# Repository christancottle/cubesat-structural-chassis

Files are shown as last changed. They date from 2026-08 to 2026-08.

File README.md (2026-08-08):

# CubeSat Structural Chassis

A CDS-compliant 1U CubeSat structural chassis — modeled, dimensioned, and structurally verified in SolidWorks over a two-week summer project. This covers the load-bearing subsystem of a CubeSat: the rail/wall chassis and internal mounting deck, built to the CalPoly CubeSat Design Specification (CDS) and verified against a launch load case using SolidWorks Simulation.

## Overview

The goal of this project was to design a real, spec-compliant CubeSat structure from scratch and take it through a complete engineering workflow: parametric CAD modeling, structural finite element analysis (FEA), a design iteration based on analysis results, and formal engineering drawings. This isn't a full CubeSat (no electronics, solar panels, or payload) — it's a focused structures deliverable, similar to what a "structures" subteam on a real CubeSat program would own.

## Design

- **Envelope:** 100 x 100 x 100 mm (1U CubeSat standard)
- **Rails:** 8.5 mm width per the CalPoly CubeSat Design Specification (minimum contact width for the P-POD dispenser), with 1 mm minimum corner fillets
- **Walls:** 1.5 mm thick aluminum panels connecting the rail posts
- **Mounting deck:** internal plate offset from the base, sized to clear the rail posts, with 4x M3 clearance holes (3.2 mm) near the corners for payload mounting
- **Material:** 6061-T6 aluminum

## Structural Analysis

**Load case:** 10g quasi-static axial acceleration (98 m/s²), representing a typical launch load factor along the tube's long axis — the same direction the rails travel through the P-POD dispenser.

**Fixtures:** the four outer side faces of the tube were fixed, as a simplification of the real rail-to-dispenser contact (the rails are flush with the walls on the outside, so the true contact patch can't be isolated as a separate face without additional split-line work — noted here as a known simplification).

**Contact:** the mounting deck is bonded to the surrounding tube structure, representing a fastened/mounted connection.

**Result:** maximum von Mises stress of 157.4 kPa against a yield strength of 275 MPa for 6061-T6 aluminum — a safety factor of roughly 1,750x.

| Design iteration | Wall thickness | Max stress | Safety factor |
|---|---|---|---|
| Baseline | 2.5 mm | 158.2 kPa | ~1,738x |
| Final | 1.5 mm (+ corner fillets added) | 157.4 kPa | ~1,747x |

**Key finding:** reducing wall thickness by 40% had almost no effect on peak stress. The mounting deck, not the tube walls, governs the peak stress in this load case — meaning the wall thickness has room for further mass optimization without compromising structural margin.

## Repository Contents

```
CAD/          SolidWorks part file (.SLDPRT) and STEP export
drawings/     Dimensioned engineering drawing (PDF)
analysis/     FEA result screenshots and summary
images/       Renders used in this README
```

## Future Work

- Use split-line features to isolate the true rail contact area for a more accurate fixture definition
- Explore relieved/L-shaped rail geometry for further mass savings
- Add additional load cases (lateral acceleration, random vibration)
- Model fasteners/standoffs explicitly rather than using a bonded contact simplification

## Tools

SolidWorks 2024/2025 (CAD), SolidWorks Simulation (FEA)

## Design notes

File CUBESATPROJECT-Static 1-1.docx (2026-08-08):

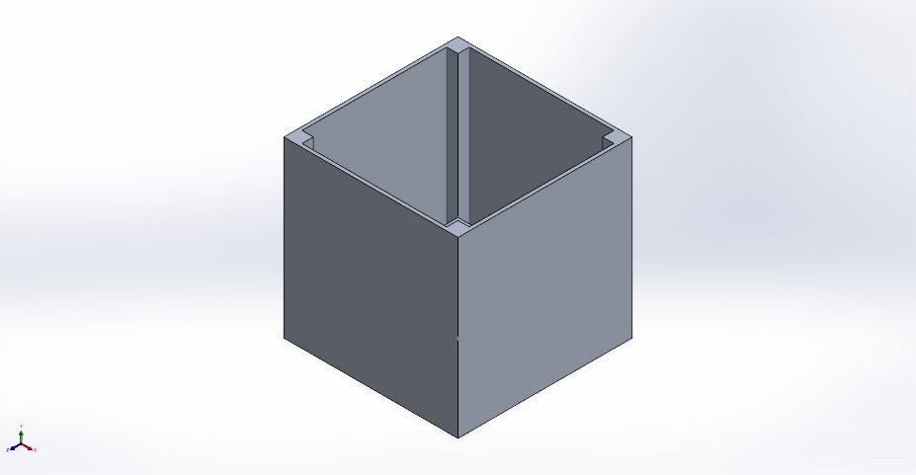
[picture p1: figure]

Simulation of CUBESATPROJECT

Date: Friday, August 7, 2026
Designer: Solidworks

Study name: Static 1

Analysis type: Static
Description No Data

# Assumptions

# Model Information

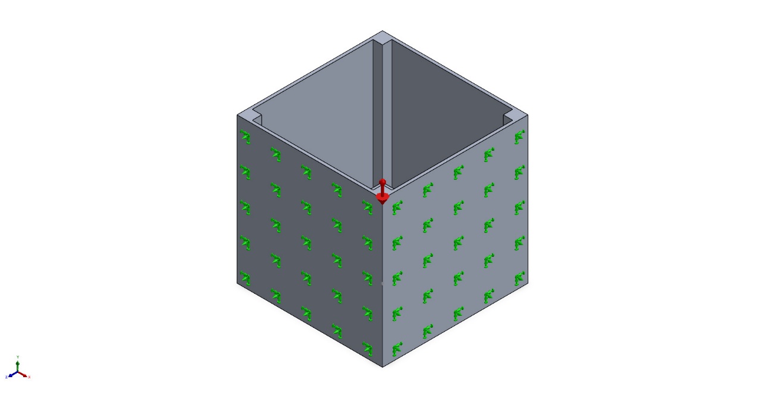
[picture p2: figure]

Model name: CUBESATPROJECT

Current Configuration: Default

Solid Bodies
Document Name and Reference | Treated As | Volumetric Properties | Document Path/Date Modified

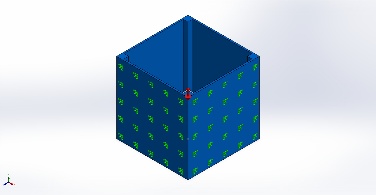
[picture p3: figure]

Boss-Extrude2 | Solid Body | Mass:0.25731 kg Volume:9.53e-05 m^3 Density:2,700 kg/m^3 Weight:2.52164 N | C:\Users\frxif\OneDrive\Documents\CUBESATPROJECT.SLDPRT Aug 6 16:11:20 2026

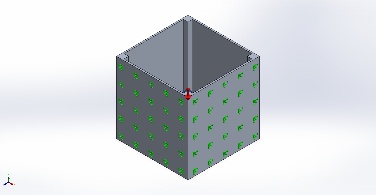
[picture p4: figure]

Boss-Extrude3 | Solid Body | Mass:0.0343863 kg Volume:1.27357e-05 m^3 Density:2,700 kg/m^3 Weight:0.336986 N | C:\Users\frxif\OneDrive\Documents\CUBESATPROJECT.SLDPRT Aug 6 16:11:20 2026

# Study Properties

Study name | Static 1
Analysis type | Static
Mesh type | Solid Mesh
Thermal Effect: | On
Thermal option | Include temperature loads
Zero strain temperature | 298 Kelvin
Include fluid pressure effects from SOLIDWORKS Flow Simulation | Off
Solver type | Automatic
Inplane Effect: | Off
Soft Spring: | Off
Inertial Relief: | Off
Incompatible bonding options | Automatic
Contact penalty stiffness scale factor | 1
Large displacement | Off
Compute free body forces | On
Friction | Off
Use Adaptive Method: | Off
Result folder | SOLIDWORKS document (C:\Users\frxif\OneDrive\Documents)

# Units

Unit system: | SI (MKS)
Length/Displacement | mm
Temperature | Kelvin
Angular velocity | Rad/sec
Pressure/Stress | N/m^2

# Material Properties

Model Reference | Properties | Components

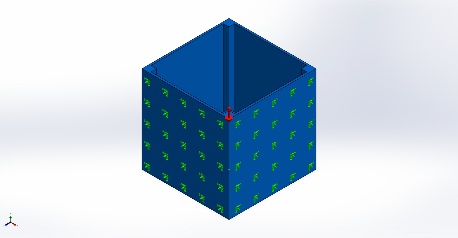
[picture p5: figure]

| Name: 6061-T6 (SS) Model type: Linear Elastic Isotropic Default failure criterion: Unknown Yield strength: 2.75e+08 N/m^2 Tensile strength: 3.1e+08 N/m^2 Elastic modulus: 6.9e+10 N/m^2 Poisson's ratio: 0.33 Mass density: 2,700 kg/m^3 Shear modulus: 2.6e+10 N/m^2 Thermal expansion coefficient: 2.4e-05 /Kelvin | SolidBody 1(Boss-Extrude2)(CUBESATPROJECT), SolidBody 2(Boss-Extrude3)(CUBESATPROJECT)

Curve Data:N/A

# Loads and Fixtures

Fixture name | Fixture Image | Fixture Details

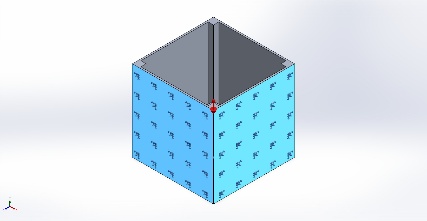
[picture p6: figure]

Fixed-1 | | Entities: 4 face(s) Type: Fixed Geometry

Resultant Forces

Components | X | Y | Z | Resultant
Reaction force(N) | -6.64717e-07 | 28.5863 | 9.26666e-07 | 28.5863
Reaction Moment(N.m) | 0 | 0 | 0 | 0

Load name | Load Image | Load Details

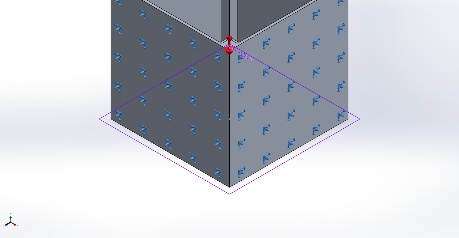
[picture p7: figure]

Gravity-1 | | Reference: Top Plane Values: 0 0 -98 Units: m/s^2

# Connector Definitions

No Data

# Interaction Information

Interaction | Interaction Image | Interaction Properties

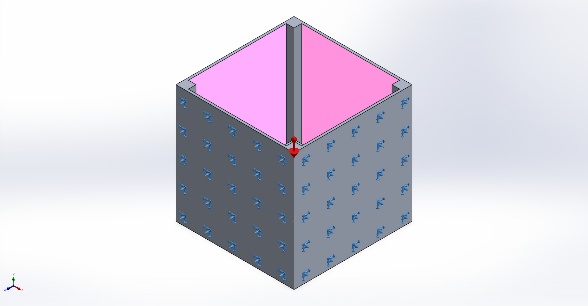
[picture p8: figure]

Local Interaction-1 | | Type: Bonded interaction pair Entities: 8 face(s)

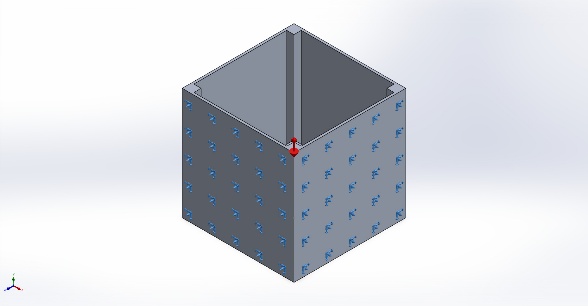
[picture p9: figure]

Global Interaction | | Type: Bonded Components: 1 component(s) Options: Independent mesh

# Mesh information

Mesh type | Solid Mesh
Mesher Used: | Blended curvature-based mesh
Jacobian points for High quality mesh | 16 Points
Maximum element size | 12.2482 mm
Minimum element size | 1.22459 mm
Mesh Quality | High

## Mesh information - Details

Total Nodes | 6879
Total Elements | 3244
Maximum Aspect Ratio | 9.5185
% of elements with Aspect Ratio < 3 | 39.1
Percentage of elements with Aspect Ratio > 10 | 0
Percentage of distorted elements | 0
Time to complete mesh(hh;mm;ss): | 00:00:01
Computer name: | BATMOBILE

## Mesh Quality Plots

Name | Type | Min | Max
Quality1 | Mesh | - | -

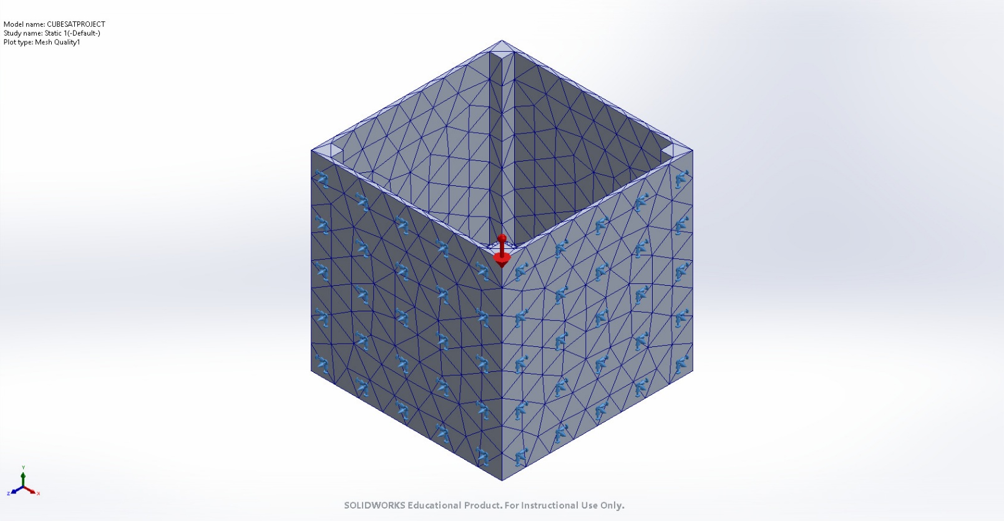
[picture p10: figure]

CUBESATPROJECT-Static 1-Quality-Quality1

# Sensor Details

No Data

# Resultant Forces

## Reaction forces

Selection set | Units | Sum X | Sum Y | Sum Z | Resultant
Entire Model | N | -6.64717e-07 | 28.5863 | 9.26666e-07 | 28.5863

## Reaction Moments

Selection set | Units | Sum X | Sum Y | Sum Z | Resultant
Entire Model | N.m | 0 | 0 | 0 | 0

## Free body forces

Selection set | Units | Sum X | Sum Y | Sum Z | Resultant
Entire Model | N | 4.84288e-08 | 18.1968 | 2.21655e-07 | 18.1968

## Free body moments

Selection set | Units | Sum X | Sum Y | Sum Z | Resultant
Entire Model | N.m | 0 | 0 | 0 | 1e-33

# Beams

No Data

# Study Results

Name | Type | Min | Max
Stress1 | VON: von Mises Stress | 1.133e-01N/m^2 Node: 2030 | 1.582e+05N/m^2 Node: 3833

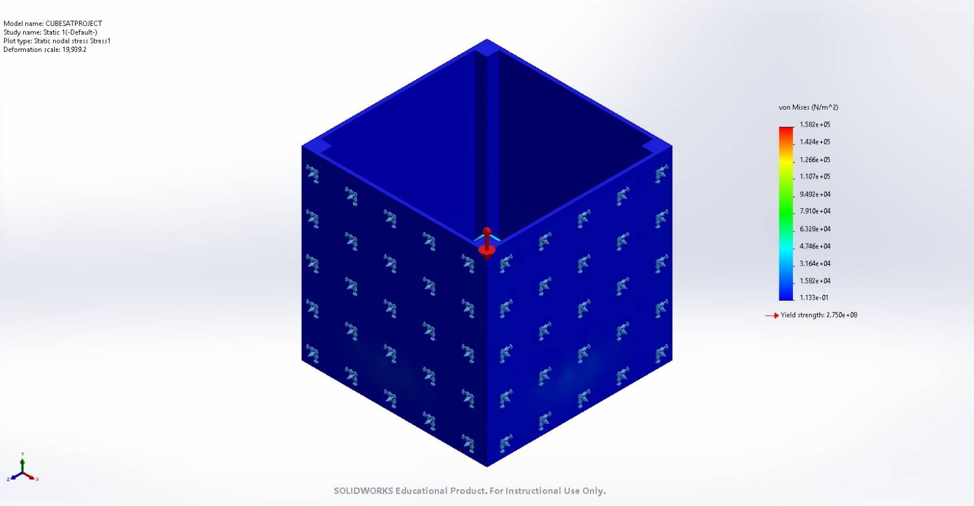
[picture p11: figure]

CUBESATPROJECT-Static 1-Stress-Stress1

Name | Type | Min | Max
Displacement1 | URES: Resultant Displacement | 0.000e+00mm Node: 1 | 5.015e-04mm Node: 6543

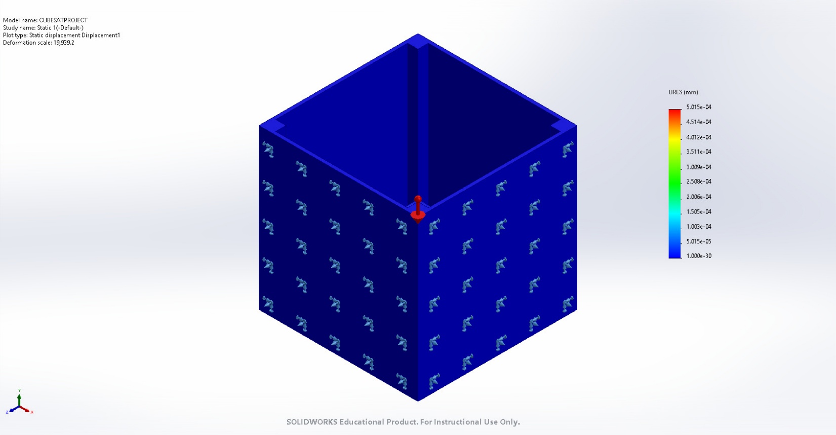
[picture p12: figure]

CUBESATPROJECT-Static 1-Displacement-Displacement1

Name | Type | Min | Max
Strain1 | ESTRN: Equivalent Strain | 1.829e-09 Element: 669 | 1.316e-06 Element: 3204

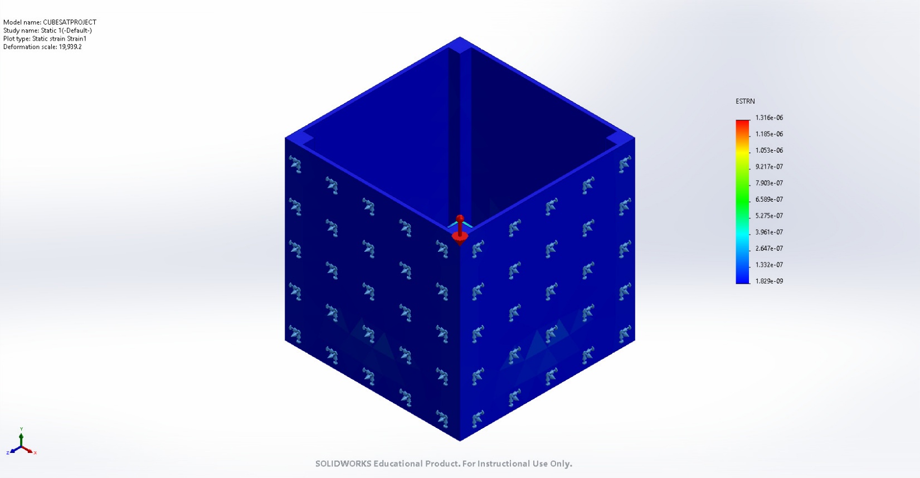
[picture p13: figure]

CUBESATPROJECT-Static 1-Strain-Strain1

# Conclusion

Analyzed with SOLIDWORKS Simulation Simulation of CUBESATPROJECT 16

Analyzed with SOLIDWORKS Simulation Simulation of CUBESATPROJECT 1

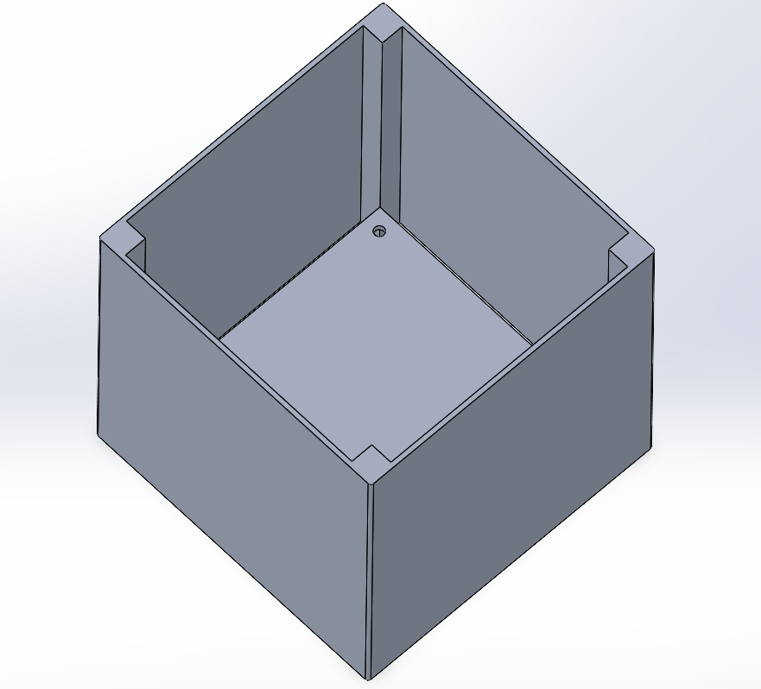
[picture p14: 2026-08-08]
Isometric View.png

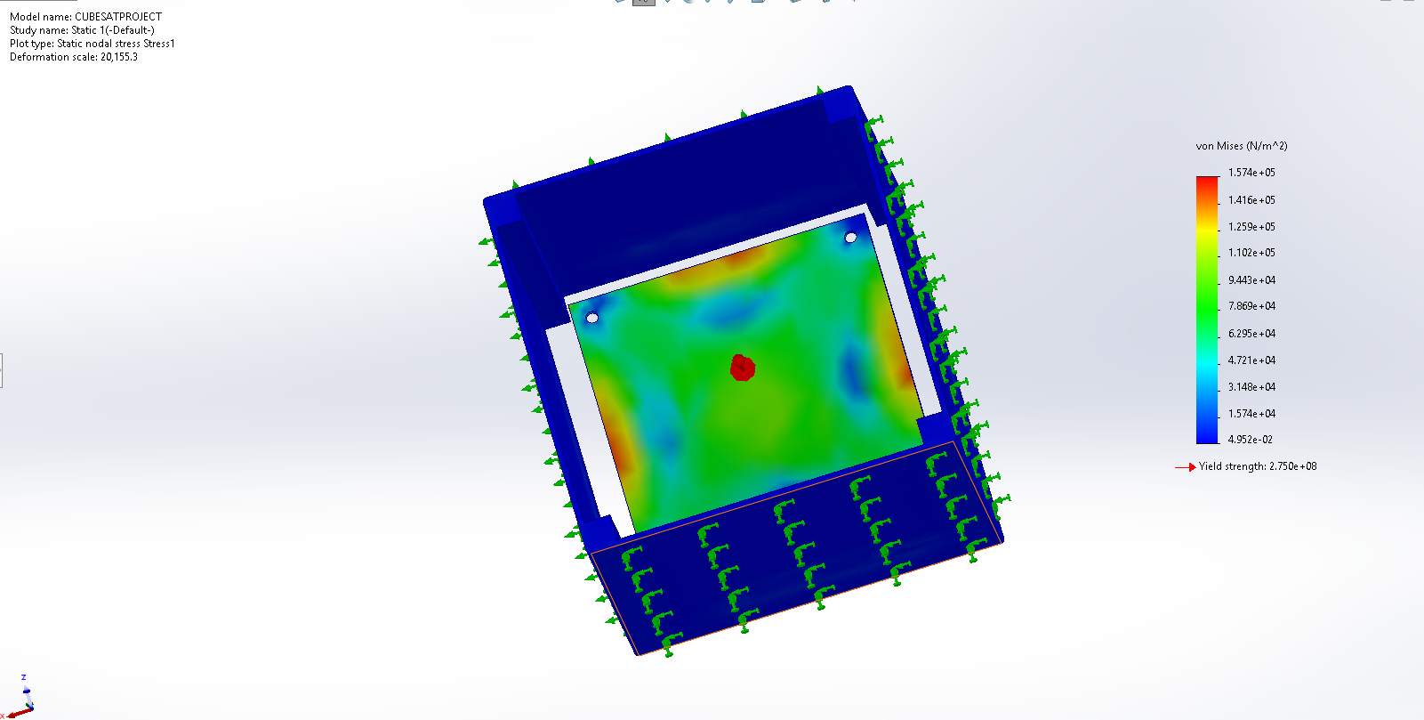
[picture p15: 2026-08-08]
CUBESATRUN2.png

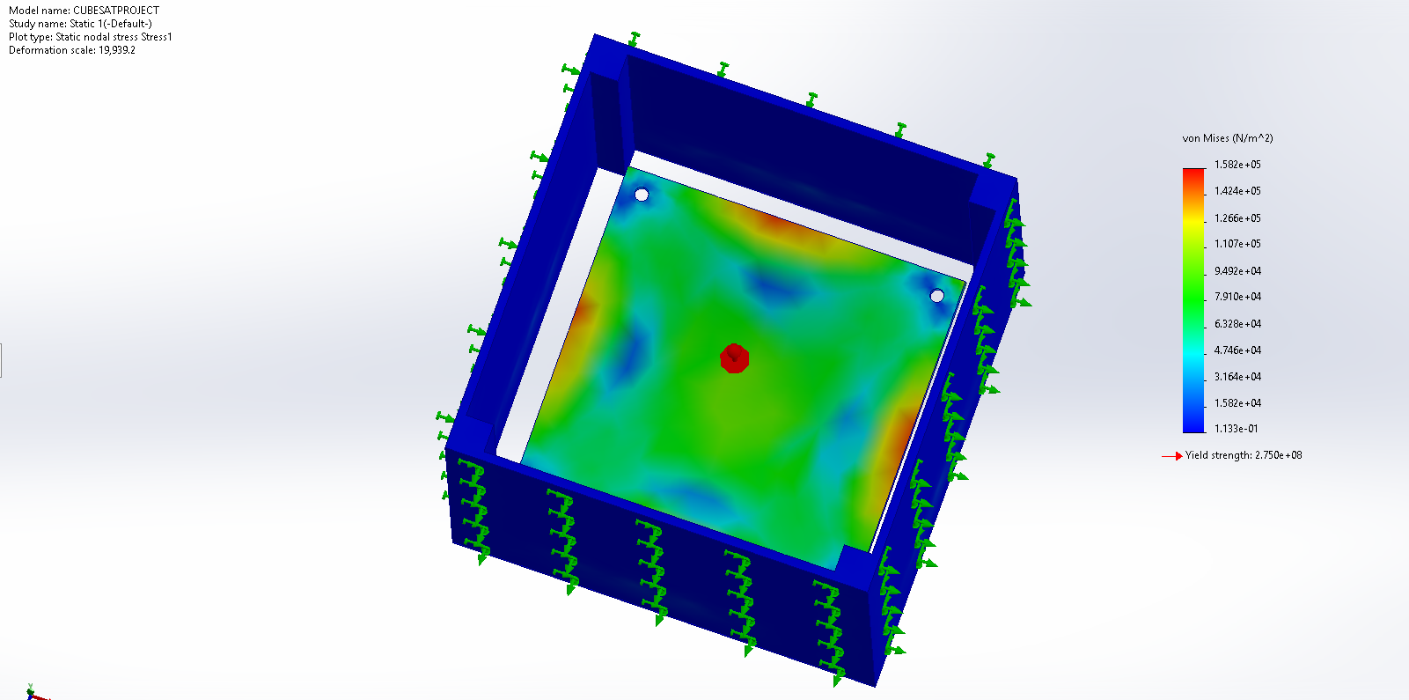
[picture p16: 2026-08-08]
CUBESATRUN1.png

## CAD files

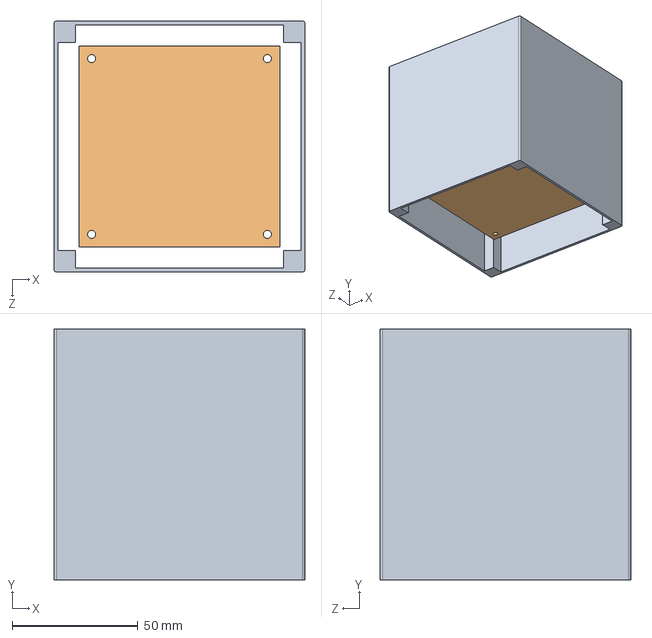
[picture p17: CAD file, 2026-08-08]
CUBESATPROJECT.STEP
100.0 x 100.0 x 100.0 mm

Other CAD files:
CUBESATPROJECT.SLDDRW
CUBESATPROJECT.SLDPRT

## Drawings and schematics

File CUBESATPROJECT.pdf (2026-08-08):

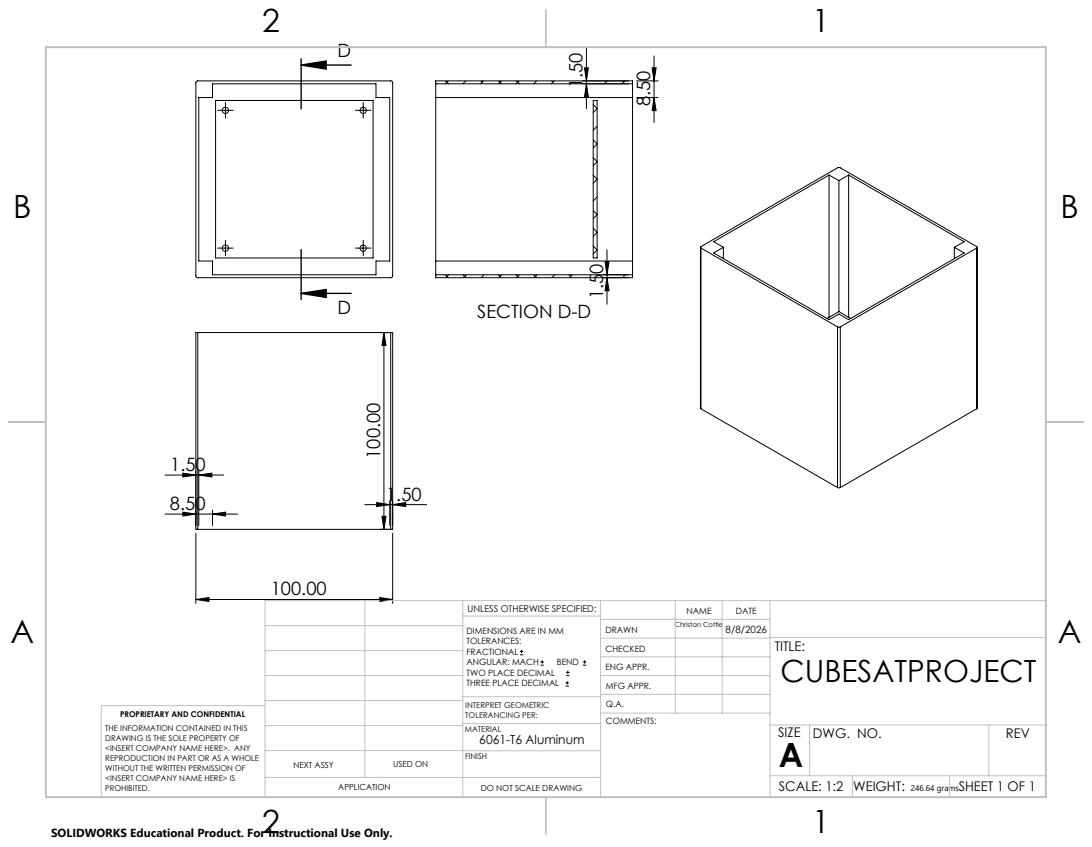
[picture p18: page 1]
SECTION D-D

UNLESS OTHERWISE SPECIFIED: | | NAME | DATE
DIMENSIONS ARE IN MM TOLERANCES: FRACTIONAL ANGULAR: MACH BEND TWO PLACE DECIMAL THREE PLACE DECIMAL | DRAWN | | 8/8/2026 Christan Cottle

CHECKED | | | TITLE: CUBESATPROJECT

ENG APPR.
MFG APPR.

INTERPRET GEOMETRIC TOLERANCING PER: | Q.A.
MATERIAL 6061-T6 Aluminum | | SIZE A | DWG. NO. | REV

PROPRIETARY AND CONFIDENTIAL
THE INFORMATION CONTAINED IN THIS
DRAWING IS THE SOLE PROPERTY OF
<INSERT COMPANY NAME HERE>. ANY
REPRODUCTION IN PART OR AS A WHOLE
WITHOUT THE WRITTEN PERMISSION OF
<INSERT COMPANY NAME HERE> IS
PROHIBITED.

NEXT ASSY | USED ON | FINISH

APPLICATION | DO NOT SCALE DRAWING | | SCALE: 1:2 | WEIGHT: 246.64 gramsSHEET 1 OF 1

SOLIDWORKS Educational Product. For Instructional Use Only.
